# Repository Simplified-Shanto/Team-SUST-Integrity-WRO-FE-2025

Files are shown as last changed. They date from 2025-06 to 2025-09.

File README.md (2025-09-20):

# 👥 About the Team – **Team SUST Integrity**
---

## 👥 **Team SUST Integrity**

- **Nayeem Islam Shanto**  – Team Leader, Hardware Developer | [islamnayeem386@gmail.com](mailto:islamnayeem386@gmail.com)
- **Dipanjan Ghosh**  –  Schematic and Documentation Developer | [priomghosh33@gmail.com](mailto:priomghosh33@gmail.com)
- **L.M. Mahir Labib** – Software Developer | [labib.programmer@gmail.com](mailto:labib.programmer@gmail.com)

**Team Origin**: Bangladesh

---
# 📑 Table of Contents  

- [👥 About the Team – Team Integral Constant](#-about-the-team--team-integral-constant)  
  - [🧠 Who We Are](#-who-we-are)  
  - [📁 Repository Structure](#-our-repository-structure)  
- [🎯 Mission Overview](#mission-overview-for-wro-future-engineers-rounds)  
  - [🏁 Round 1: Lap Completion (Open Round)](#-round-1-lap-completion-open-round)  
  - [🚧 Round 2: Obstacle Challenge Round](#-round-2-obstacle-challenge-round)  
- [🧩 Hardware Components](#-hardware-components)  
- [🚗 Mobility Management](#-mobility-management)  
  - [🦾 Rear Axle Power Distribution](#-rear-axle-power-distribution)  
  - [🔁 Differential System](#-differential-system)  
  - [🧭 Steering Mechanism](#-steering-mechanism)  
- [💻 Raspberry Pi Setup](#-setting-up-raspberry-pi-for-image-processing-with-opencv--python)  
  - [🔑 Enabling & Using VNC](#-enabling--using-vnc-on-raspberry-pi)  
  - [🔎 Static COM Port Setup](#-how-to-set-static-com-port-for-the-low-level-microcontroller)  
  - [📷 Test Webcam Feed](#test-your-webcam-feed)  
  - [⚡ Auto-start Python Script](#running-your-python-script-on-startup-of-raspberry-pi)  
  - [🔌 Safe Shutdown via Serial](#safe-shutdown-for-raspberry-pi-via-serial-command)  
- [🧪 Testing & Calibration](#-testing--calibration)  
- [🔐 Safety Considerations](#-safety-considerations)  
- [🧑‍💻 Obstacle Challenge Strategy](#-strategy-for-the-obstacle-challenge-round)  

---

### 🧠 Who We Are

We are a group of passionate young engineers from Bangladesh, driven by curiosity, creativity, and a love for solving real-world problems with technology. Each team member plays a crucial role — from mechanical design to software development to integration testing.

This project reflects not just our technical skills, but our teamwork, perseverance, and belief in building meaningful things with limited resources.

---

### 📁 Our Repository Structure

To keep everything organized and transparent, we structured this GitHub repo with clarity and purpose. Here’s what each folder contains:

- `t-photos/`: Our official team photo and a fun team moment — because engineering is serious fun.
- `v-photos/`: Photos of the robot from all angles — top, bottom, front, back, sides — for full transparency.
- `video/`: Link to our demo and performance video.
- `schemes/`: Wiring and circuit diagrams, showcasing all sensors, modules, and power connections.
- `src/`: All the source code we wrote for robot control, sensors, PID logic, lap counting, and obstacle handling.
- `models/`: 3D printable parts, like sonar mounts and brackets — modeled in Autodesk Fusion 360.
- `Mobility Management/`: Our approach to movement — motor selection, differential system, steering design, and engineering principles.
- `Power and Sense Management/`: Detailed write-up of how power is distributed and how sensors are placed and calibrated.
- `Obstacle Management/`: Strategy for handling red and green blocks, including servo positioning and avoidance decisions.
- `other/`: Extra docs, debugging notes, component datasheets, or setup manuals — basically everything we couldn’t categorize neatly but didn’t want to lose.

---

### Mission Overview for WRO Future Engineers Rounds

<table>
  <tr>
    <td width="50%" valign="top" align="left">
      <h3>🏁 Round 1: Lap Completion</h3>
      <p>In <strong>Round 1</strong>, the robot must autonomously complete <strong>three laps</strong> on a pre-defined track. The goal of this round is for the bot to demonstrate stable navigation and precise lap tracking without any obstacle avoidance requirements.</p>
      <ul>
        <li><strong>Objective</strong>: Complete three laps on the track within the allotted time.</li>
        <li><strong>Key Tasks</strong>: Accurate path-following, speed control, and lap counting.</li>
      </ul>
      <div align="center">
        <br><br><br><br><br>
        Round 1 WRO Track
      </div>
    </td>
    <td width="50%" valign="top" align="left">
      <h3>🏆 Round 2: Lap Completion with Obstacle Avoidance and Parking</h3>
      <p>In <strong>Round 2</strong>, the bot must complete <strong>three laps</strong> while avoiding green and red obstacles:</p>
      <ul>
        <li><strong>Green Obstacles</strong>: The bot should move <strong>left</strong> to avoid.</li>
        <li><strong>Red Obstacles</strong>: The bot should move <strong>right</strong> to avoid.</li>
      </ul>
      <p>After completing the laps, the bot must accurately park within a designated zone.</p>
      <ul>
        <li><strong>Objective</strong>: Complete three laps, avoid obstacles, and park in the designated area.</li>
        <li><strong>Tasks</strong>: Obstacle detection, color-based avoidance, and precision parking.</li>
      </ul>
      <div align="center">
        Round 2 WRO Track
      </div>
    </td>
  </tr>
</table>

---
>[!IMPORTANT]
>**Important: WRO Future Engineers Rulebook**
>* **Thorough Reading:** Ensure that you thoroughly read the **WRO Future Engineers 2025 Rulebook** to understand all rules and guidelines.
>* **Official Link:** Access the rulebook here: [🔗 WRO Future Engineers 2025 Rulebook]([https://wro-association.org/competitions/future-engineers/](https://wro-association.org/wp-content/uploads/WRO-2024-Future-Engineers-Self-Driving-Cars-General-Rules.pdf).

---

# Strategy for the Challenge Rounds

## 👩‍💻 Strategy for the Open Challenge Round

In this round we mainly used sonar sensors to determine the position of the robot during driving straight and turning. We used a webcam for lap counting and also as a failsafe method for determining the position
of the robot when the data sent by the sonar sensors is inconsistent or in case of any malfunction.

- After starting the program the robot determines its placement on the track and its round direction(clockwise or anticlockwise).
- The sonar sensors attached to both sides of the robot help the robot to keep its position always at the center and the one attached in front of the robot helps it to turn smoothly by giving it ample data.
It is set to always turn right when round direction is clockwise and left when anticlockwise.
- The webcam mainly helps count the orange lines on the track to keep record of laps. After robot counts 12 orange lines(4 orange line = 1 lap) it determines the end of 3 laps.
- After traversing 3 laps it stops at its initial position after a certain amount of delay.

## 🏁 Round 1: Lap Completion (Open Round)

Here’s the process flow of how the robot completes laps in Round 1:

Open Round Process

---

## 🧑‍💻 Strategy for the Obstacle Challenge Round

Our current strategy for the Obstacle Challenge round is to avoid obstacles by changing the setpoint in the PID loop of our robot's main program.

- After the program starts the robot would at first determine the round direction(clockwise or anticlockwise) by observing which line(either orange or blue) comes first
- Then when it encounters a red object, it changes its setpoint from being into the middle towards the right wall(10 cm away from the right wall). The same approach is followed in case of a green object, only the difference being that it now follows the left wall.
- If it does not encounter any object the setpoint is again set to the center.

## 🚧 Round 2: Obstacle Challenge Round

Here’s the process flow of how the robot avoids obstacles in Round 2:

Obstacle Round Process

---

We built this robot and documentation not just for a competition, but to share, inspire, and collaborate. If you’re here to learn, contribute, or replicate — welcome to the constant.

# 🧩 Hardware Components

<div align="center">

| Component | Quantity | Image |
|---|:---:|:-----:|
| **Raspberry Pi 4B** | 1x |  |
| **ESP32 Dev Board** | 1x |  |
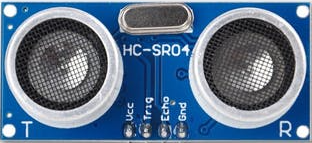
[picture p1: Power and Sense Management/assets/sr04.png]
| **HC-SR04 Ultrasonic Sensor** | 4x |  |
| **Raspberry Pi Camera Module** | 1x |  |
| **L298N Motor Driver Module** | 1x |  |
| **XL4016 Buck Converter** | 1x |  |
| **XL6009 Boost Converter** | 1x |  |
| **MG90S Micro Servo Motor** | 1x |  |
| **25GA 800RPM DC Geared Motor** | 1x |  |
| **MPU6050 Gyroscope Sensor** | 1x |  |

</div>
---

# 🚗 Mobility Management

Mobility is at the heart of our robot's design. We aimed to create a drive and steering system that mimics real-world vehicles while optimizing for speed, torque, and control on WRO tracks.

---

## 🦾 Rear Axle Power Distribution

We designed our rear-wheel drive system around **realistic mechanical dynamics**, utilizing a **LEGO differential gear** instead of a solid axle. This allows each wheel to rotate at different speeds during turns — just like in real cars — improving traction and reducing drag.

### 🔧 Motor Selection:
- We first experimented with standard **TT motors**, but they lacked the torque and RPM needed.
- We upgraded to **25GA 800 RPM DC geared motors**, which offer high torque and fast rotation, suitable for both lap completion and obstacle navigation.

---

## 🔁 Differential System

A **LEGO differential gear** is used on the rear axle. This gear allows independent rotation of the left and right wheels, providing:
- ✅ Smoother turning
- ✅ Reduced wheel slippage
- ✅ Real-world vehicle behavior emulation

The differential is connected directly to the 25GA motor, delivering balanced torque to both wheels.

---

## 🧭 Steering Mechanism

### ⚙️ Initial Design: Ackermann Steering

We initially implemented an **Ackermann Steering System**, commonly used in real vehicles. This system allows the inner and outer wheels to turn at different angles during cornering, minimizing slip and improving efficiency.

**Advantages:**
- ✅ Realistic turning geometry
- ✅ Efficient tire rotation paths

However, the mechanical complexity and setup space required made it difficult to tune within our chassis design.

---

### 🔄 Final Design: Rack and Pinion Steering

To simplify the design and enhance control, we transitioned to a **Rack and Pinion** steering system. This setup:
- Converts rotational motion from the steering motor to linear motion to turn the wheels
- Is simpler to mount and tune
- Offers consistent steering angles and tighter control

**Powered by:** Servo motor controlled by Raspberry Pi GPIO pins

---

## 🛠️ Chassis & Assembly Notes

- **Material**: Custom 3D printed base + LEGO Technic frame
- **Design Tools**: Autodesk Fusion 360 (for custom parts like sonar mounts, motor brackets)
- **Mounting Strategy**:
  - Front: Rack and pinion + servo motor
  - Rear: 25GA motor with LEGO differential
  - Components are evenly distributed for optimal center of mass

---

---

# 🚀 Setting Up Raspberry Pi for Image Processing with OpenCV & Python

You just unboxed a brand-new **Raspberry Pi**. Exciting! 🎉
Now let’s get it ready for image processing projects with OpenCV and Python.

---

## 🛠️ Initial Setup

1. **Download & Install Raspberry Pi Imager** on your computer.
2. In the **OS configuration menu**, set the following:

   * ✅ Hostname
   * ✅ Username
   * ✅ Password
   * ✅ Wi-Fi SSID & Password
   * ✅ Enable SSH
3. ✍️ Write down these credentials — you’ll need them for remote login later.
4. Once the OS image is written, insert the SD card into your Raspberry Pi and let it boot up.

---

## 🎮 Two Ways to Use Your Raspberry Pi

* **Option A**: Connect directly with an HDMI display, keyboard, and mouse.
* **Option B**: Connect remotely from your laptop/PC via **VNC (Virtual Network Computing)**.

We’ll focus on Option B since it’s super handy.

---

# 🔑 Enabling & Using VNC on Raspberry Pi

## 📡 Process 1: Connect via Ethernet Cable

1. Plug an **Ethernet cable** between your Raspberry Pi and your computer.
2. Wait until the **LAN port LEDs blink** — connection established!
3. On your computer, open **Command Prompt/Terminal**.
4. Type:

   ```bash
   ssh username@hostname
   ```

   Example:

   ```bash
   ssh admin@raspi.local
   ```
5. Enter your password when prompted.

💡 **What is SSH?**
SSH (Secure Shell) is a secure protocol that lets you remotely access and manage systems over a network. It encrypts communication to protect your data.

6. Once logged in, run:

   ```bash
   sudo raspi-config
   ```

   This opens a configuration menu:
   raspi-config-menu

7. Navigate to:
   **3 Interfacing Options → P3 VNC → Enable**
   enable-vnc

8. **Reboot** your Raspberry Pi.

9. On your computer, install & open **RealVNC Viewer**.

10. In the search bar, enter your Pi’s **hostname** (e.g., `raspi.local`).

11. First-time login will prompt for **username & password** → tick **“Remember Password”** if desired.

12. 🎉 You should now see the Raspberry Pi’s desktop GUI!

---

## 📶 Process 2: Connect via Wi-Fi (Wireless LAN)

1. Ensure your **Raspberry Pi** and **computer** are on the **same Wi-Fi network**.

   * If using a mobile hotspot, configure it with the same SSID & password you set during OS imaging.
2. Find your Raspberry Pi’s **IP address** on the network.

   * Tools like **Net Analyzer** (mobile app) make this easy.
3. From your computer, open Command Prompt/Terminal and type:

   ```bash
   ssh username@<raspberry-pi-ip>
   ```

   Example:

   ```bash
   ssh admin@10.149.112.111
   ```

   (Note: Here we use the **IP address**, not the hostname.)
4. Follow **Steps 7–12** from **Process 1** to enable VNC.
5. In RealVNC Viewer, enter the Pi’s **IP address**.
6. Log in with your username & password → check **“Remember Password”** if desired.
7. 🎉 The Raspberry Pi’s GUI should now appear on your computer!

---

✨ With VNC ready, you now have full graphical access to your Raspberry Pi — perfect for running **Python + OpenCV** image processing projects remotely!

---


  
   
   

# How to set static com port for the low level microcontroller?

---

## 🔎 Step 1: Plug in your ESP32 and identify it

First, connect your ESP32 to your Raspberry Pi’s USB port.
Then, open a terminal and run:

```bash
lsusb
```

You’ll see a list of connected USB devices, like this:


Take note of the **Vendor ID** (`1a86`) and **Product ID** (`7523`). These are your device’s fingerprints!

Now, let’s find its **serial number** (optional but recommended). Run:

```bash
udevadm info -a -n /dev/ttyUSB0
```

*(Replace `/dev/ttyUSB0` with the actual port assigned to your ESP32.Use the following command to find that)*


Look for lines like:

```
ATTRS{idVendor}=="1a86"
ATTRS{idProduct}=="7523"
ATTRS{serial}=="0001"  # Example
```

If your device has a serial number, use it to **uniquely identify** it, especially if you have multiple ESP32s.

---

## ✍️ Step 2: Create the udev rule

Create a new rule file in `/etc/udev/rules.d/`.
You can call it something like:

```bash
sudo nano /etc/udev/rules.d/99-esp32.rules
```

Inside, add this line (replace with your actual values):

```
SUBSYSTEM=="tty", ATTRS{idVendor}=="1a86", ATTRS{idProduct}=="7523", SYMLINK+="esp32_serial"
```

If you have a serial number too, add that:

```
SUBSYSTEM=="tty", ATTRS{idVendor}=="1a86", ATTRS{idProduct}=="7523", ATTRS{serial}=="0001", SYMLINK+="esp32_serial"
```

This means:

* Whenever a device with **Vendor ID 1a86** and **Product ID 7523** is connected, udev will create a **symlink** (like an alias) at `/dev/esp32_serial`.

---

## 🔄 Step 3: Reload udev and test it

Reload udev rules:

```bash
sudo udevadm control --reload-rules
```

Then **unplug and plug back** your ESP32.

Check:

```bash
ls -l /dev/esp32_serial
```

You should see something like:

```
lrwxrwxrwx 1 root root 7 Jun 10 16:23 /dev/esp32_serial -> ttyUSB0
```

(Or whatever tty device it points to.)

---

## 🐍 Step 4: Use it in your Python script

Now, in your script:

```python
import serial

ser = serial.Serial('/dev/esp32_serial', 115200)
```

This way, no matter what port it lands on—`ttyUSB0`, `ttyUSB1`, `ttyACM0`—you’ll always connect using `/dev/esp32_serial`.

---

# Install python modules like opencv, numpy, time, pyserial using following command: 
sudo apt install python3-opencv python3-numpy python3-serial

## 🚀 Pro Tips

✅ If your ESP32 shows up as `/dev/ttyACM0` instead of `/dev/ttyUSB0`, adjust your `udevadm info` command accordingly.
✅ Use `udevadm monitor` to see real-time device events:

```bash
udevadm monitor --udev
```

---

---

## Test Your Webcam Feed

Before running the full OpenCV script, it’s important to make sure your camera is working properly. This avoids unnecessary debugging later if the issue is just with the webcam feed.

### Steps:

1. Make sure your Raspberry Pi is set up and your webcam is connected.

2. Install OpenCV for Python (if not already done):

   ```bash
   pip install opencv-python
   ```

3. Create a new Python file called `test_camera.py` and paste the following code:

   ```python
   import cv2

   cap = cv2.VideoCapture(0)  # 0 is usually the default camera

   if not cap.isOpened():
       print("Error: Could not open camera.")
       exit()

   while True:
       ret, frame = cap.read()
       if not ret:
           print("Error: Failed to capture frame.")
           break

       cv2.imshow("Webcam Feed", frame)

       # Press 'q' to exit the window
       if cv2.waitKey(1) & 0xFF == ord('q'):
           break

   cap.release()
   cv2.destroyAllWindows()
   ```

4. Run the script:

   ```bash
   python test_camera.py
   ```

5. A window should pop up showing your live webcam feed.

   * If you see the video feed, your camera is working fine.
   * If you don’t, check if your camera is properly connected and detected by the system using:

     ```bash
     ls /dev/video*
     ```

---

---

# Running your Python Script on Startup of Raspberry Pi

If you want your Python script to automatically run when your Raspberry Pi boots up (without needing a monitor, keyboard, or VNC), follow these steps. We’ll use a **systemd service**, which is the recommended modern way.

---

## 1. Locate Your Script

Make sure your Python script is at the correct path. In this guide, we’ll assume your script is here:

```
/home/admin/Desktop/startscript.py
```

Check that the script has a proper shebang at the top (this tells Linux to use Python 3):

```python
#!/usr/bin/env python3
```

---

## 2. Make the Script Executable

Run this command in the terminal:

```bash
chmod +x /home/admin/Desktop/startscript.py
```

---

## 3. Create a systemd Service File

Create a new service definition:

```bash
sudo nano /etc/systemd/system/startscript.service
```

Paste the following:

```ini
[Unit]
Description=Startscript for Line Counter
After=multi-user.target

[Service]
ExecStart=/usr/bin/python3 /home/admin/Desktop/startscript.py
WorkingDirectory=/home/admin/Desktop
StandardOutput=append:/home/admin/startscript.log
StandardError=append:/home/admin/startscript.log
Restart=always
RestartSec=5
User=admin

[Install]
WantedBy=multi-user.target
```

If you want the program run once per boot, make Restart=no and remove the line RestartSec=5. 
This won't allow it to rerun the program if it ends its execution by some internal logic, command or crashes in the same boot session. 

Save and exit (`CTRL+O`, `ENTER`, `CTRL+X`).

---

## 4. Enable the Service

Reload systemd and enable your new service so it runs on every boot:

```bash
sudo systemctl daemon-reload
sudo systemctl enable startscript.service
```

You can start it immediately (without rebooting) using:

```bash
sudo systemctl start startscript.service
```

---

## 5. Check Logs and Status

* Check if your script is running:

  ```bash
  systemctl status startscript.service
  ```
* View live logs:

  ```bash
  journalctl -u startscript.service -f
  ```
* Or check the saved log file:

  ```bash
  cat /home/admin/startscript.log
  ```

---

## 6. Stop or Disable Later

To stop the script from running:

```bash
sudo systemctl stop startscript.service
```

To remove it from startup:

```bash
sudo systemctl disable startscript.service
```

---

✅ That’s it! Your Python script will now start automatically whenever your Raspberry Pi boots up — even without HDMI or network connected.

---

# Safe Shutdown for Raspberry Pi via Serial Command

Normally, if you unplug the power from your Raspberry Pi without shutting it down first, you risk corrupting the SD card or losing data. To prevent this, the Pi should always be shut down properly before the power is removed.

In this setup, we achieve a graceful shutdown without needing a display (HDMI) or remote access (VNC/SSH).

How it works

A low-level microcontroller (e.g., Arduino/ESP) detects a trigger event (such as a button press, sensor signal, or external condition).

It sends a shutdown command over Serial (UART/USB) to the Raspberry Pi.

A Python script running on the Pi (using PySerial
) listens for this command.

Once received, the script executes:

sudo shutdown now

The Pi powers down safely, protecting the filesystem and ensuring no data loss.

Why this matters

✅ Prevents SD card corruption caused by abrupt power cuts

✅ Works without a monitor, keyboard, or VNC session

✅ Can be triggered by just a button press or any hardware event handled by the microcontroller

---
## 🧪 Testing & Calibration

- ✅ PID tuning done for lap accuracy
- ✅ Rack and pinion tested for max steering angle and stability
- ✅ Motors calibrated for obstacle response delay and RPM

---

## 🔐 Safety Considerations

- All electrical joints are soldered and insulated
- Gear systems are housed to prevent accidental entanglement
- Battery is securely mounted with a cutoff mechanism

---

By combining a **25GA high-RPM motor**, **LEGO differential**, and a **custom rack and pinion system**, our robot delivers realistic movement, efficient turning, and powerful drive — ready for the WRO Future Engineers challenge.

---

## 📜 License

© 2025 Team SUST Integrity – WRO Future Engineers  
This project is licensed under the [MIT License](LICENSE).

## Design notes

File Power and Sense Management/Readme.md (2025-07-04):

**Power and Sense Management**
====
In the realm of robotics, effective power and sense management is the linchpin of our robot's performance. Our cutting-edge system ensures optimal resource allocation, revolutionizing how robots interact with their surroundings.

## 1. Power Management: 

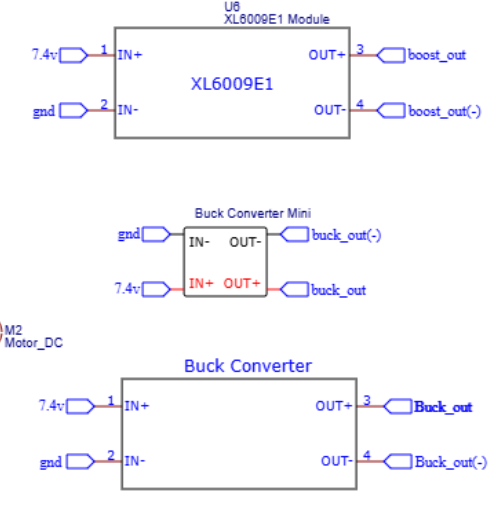
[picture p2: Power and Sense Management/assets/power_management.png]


   At first from lithium ion cell we are fetching 3.7v and being 12v by XL60009. then HW-411A LM2596 are cosuming power to 3.3v for the sensor e.g. Pi Camera, SR04 ultrasonic sensor and gyro-sensor MPU 6050.  Laterby we are suplying 5v to servo 12v to BTS7960 and motor being powered to.
## 2. Sensors: 
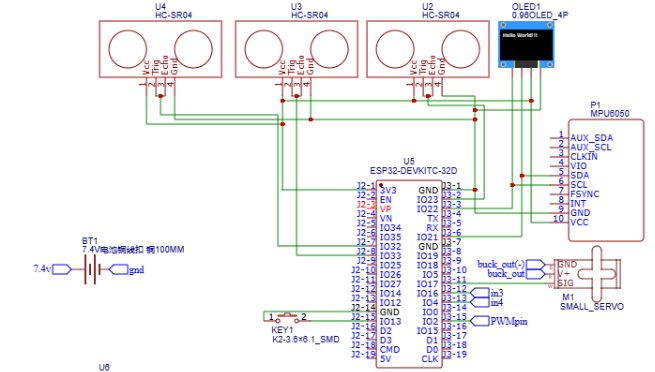
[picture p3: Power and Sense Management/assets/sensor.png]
Sensor


- #### **Ultrasonic Sensor:**
   

   The SR04 is an ultrasonic distance sensor used for measuring distances. We're powering it with a stable 5V supply obtained from an HW-411A LM2596 voltage regulator connected to an 11.1V LiPo battery. This setup ensures reliable distance measurements and efficient power management for our robot.

- #### **Pi Camera:**
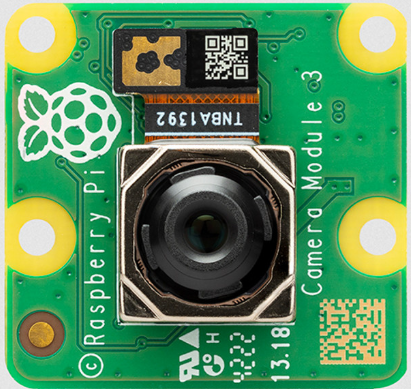
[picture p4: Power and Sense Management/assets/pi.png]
  

The Raspberry Pi Camera is a high-definition vision module capable of capturing images and streaming video, commonly used in robotics and computer vision applications. In our configuration, we use the Raspberry Pi Camera Module connected to a Raspberry Pi 4B, which serves as the core processing unit for advanced image processing tasks. The camera interfaces directly with the Raspberry Pi via the CSI (Camera Serial Interface) port, enabling high-speed data transfer. 
- #### **gyro-sensor:**
  MPU

The MPU6050 is a popular gyro-sensor and accelerometer sensor used for motion sensing and orientation tracking in various applications, including robotics and motion-controlled devices. In our setup, the MPU6050 is powered by a 5V supply sourced from an ESP32 Dev Board, which itself receives power from an HW-411A LM2596 voltage regulator. This HW-411A LM2596 regulator is connected to an XL60009 module, and the entire system is powered by an 3.7V lithium ion cell.

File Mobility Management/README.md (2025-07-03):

# Mobility Management

In the realm of mobility management for our vehicle, we meticulously select and implement motors based on engineering principles like speed, torque, and power, while also considering chassis design and component mounting for optimal performance. Assembly instructions and 3D CAD files are available for easy part fabrication.

## Motor Selection and Implementation:

### 1. Motor Selection:
- We initially experimented with **TT motors**, but they did not meet the required torque and speed benchmarks.
- Upgraded to **24GA 800 RPM DC Geared Motors**, offering improved torque output and higher rotational speed for stable and responsive movement.
- To replicate real-world vehicle behavior, we used a **LEGO differential gear** on the rear axle instead of a solid axle. This allows the rear wheels to rotate at different speeds during turns, providing smoother and more realistic cornering.

### 2. Motor Controller:
- The **L298N motor driver** was selected for its high current capacity and smooth PWM-based motor control.
- Integrated seamlessly with our **ESP32-based** microcontroller.

### 3. Implementation:
- Motors were wired to the motor driver, and the driver was interfaced with the ESP32 Dev Board.
- The rear axle was integrated with a LEGO differential system to enable differential wheel speeds during turning.

---

## Front Axle Steering System:

- Initially, we implemented an **Ackermann steering geometry**, which is known for replicating realistic vehicle steering angles and minimizing tire slippage during turns.
- After testing, we transitioned to a **Rack and Pinion steering system**, which offered better mechanical simplicity and precision for our use case.
- The rack and pinion system was designed using 3D CAD software and fabricated to ensure tight control over steering angle and response.

---

## Chassis Design and Selection:

### 1. Chassis Material:
- Constructed from **plastic base material** to ensure weightlessness and durability.

### 2. Chassis Shape:
- Optimized to accommodate all internal components while maintaining stability and proper ground clearance.

### 3. Mounting Components:
- Components were strategically arranged for even weight distribution and accessibility.
- Major mounted components include:
  - 24GA Motors with LEGO Differential Gear
  - Rack and Pinion Steering Mechanism
  - Ultrasonic and IR Sensors
  - MPU6050 Gyroscope Sensor
  - Pi Camera
  - ESP32-based Control Board
  
### 4. Engineering Principles:
- Careful calculation of **center of mass**, **wheelbase**, and **track width** to ensure stability and effective turning.
- The differential and rack & pinion systems improved the maneuverability and reduced strain on tires during sharp turns.

---

## Building and Assembly Instructions:

### 1. Step-by-Step Assembly:
- Detailed step-by-step guide covering chassis assembly, drivetrain mounting, and steering linkage.
- Wiring diagrams are provided for connecting all sensors, motors, and control components.

### 2. 3D Printed Parts:
- Custom-designed components (e.g., sonar mount, wheel rims, rack gear) were modeled using **Autodesk Fusion 360**.
- STL files and recommended materials/settings are available in the `models/` directory.

### 3. Testing and Calibration:
- Procedures for:
  - Steering calibration (center alignment, turning angles)
  - Motor speed tuning
  - Sensor data verification and orientation

### 4. Safety Considerations:
- Emphasized safety while handling LiPo batteries, high-speed motors, and voltage converters.
- All exposed connections were insulated and stress-tested under load.

---

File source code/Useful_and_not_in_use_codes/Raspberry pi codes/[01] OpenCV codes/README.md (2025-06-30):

Distance calculation logic
---

### 🔍 **Core Formula Used**

```python
distance_cm = (KNOWN_WIDTH_CM * FOCAL_LENGTH) / perceived_width_px
```

This is based on the **pinhole camera model** from computer vision.

---

### 🎯 What Each Term Means:

| Term | Explanation |
| --- | --- |
| `KNOWN_WIDTH_CM` | Real-world width of the object (10 cm for WRO traffic signs) |
| `FOCAL_LENGTH` | Calibrated or estimated focal length of the camera in pixels |
| `perceived_width_px` | Width of the object in the image (bounding box) — measured in pixels |

---

### 🧠 **The Logic Behind It**

From the geometry of a pinhole camera:

$$
\frac{\text{Real Width (cm)}}{\text{Image Width (px)}} = \frac{\text{Real Distance (cm)}}{\text{Focal Length (px)}}
$$

Rearranged:

$$
\text{Distance (cm)} = \frac{\text{Real Width (cm)} \times \text{Focal Length (px)}}{\text{Image Width (px)}}
$$

---

### 📏 Why This Works here

Since your traffic signs are **known and consistent in size (10 cm width)**, this formula works beautifully — assuming:

* The sign is facing the camera.
* There’s not too much tilt or perspective distortion.
* You’ve calibrated the `FOCAL_LENGTH` once using a known object at a known distance.

---

### 🎨 What About Aspect Ratio?

The aspect ratio check here:

```python
if not (1.6 <= rect_aspect <= 2.4):
    continue
```

✅ **Purpose**:
To filter out **false positives** — ensuring that the shape found in the frame **looks like the real traffic sign**, which has a **2:1 aspect ratio** (height\:width or vice versa depending on orientation).

So you're not using the aspect ratio **in the distance formula**, but rather as a **guard** before measuring distance — to avoid calculating distances to random rectangles like tiles, floor patterns, or odd shadows.

---

### 📸 About Focal Length: How Is `700` Chosen?

The value `700.0` is not universal — it’s typically:

  * **Estimated experimentally**, by measuring an object of known width at a known distance and solving:

  $$
  \text{Focal Length (px)} = \frac{\text{Perceived Width (px)} \times \text{Distance (cm)}}{\text{Real Width (cm)}}
  $$

  * Or derived via camera calibration if you're being fancy.

📏 **Quick way to calibrate** with your 10 cm column:

* Place it exactly 50 cm from the camera.
* Measure its bounding box width on the image: e.g. 35 pixels.
* Use:

$$
\text{FOCAL LENGTH} = \frac{35 \times 50}{10} = 175.0
$$

So your `700.0` might assume a different scale or higher-resolution camera — feel free to recalibrate!

---

###  Summary:

* ✅ **Aspect ratio**: used as a filter to ensure you’re detecting the right-shaped object (around 2:1 like your columns).
* ✅ **Focal length**: used to convert image width in pixels into a real-world distance in centimeters.
* ✅ **Distance logic**: classic pinhole camera projection formula, ideal when you know the real object size (which WRO gives you 😎).

---

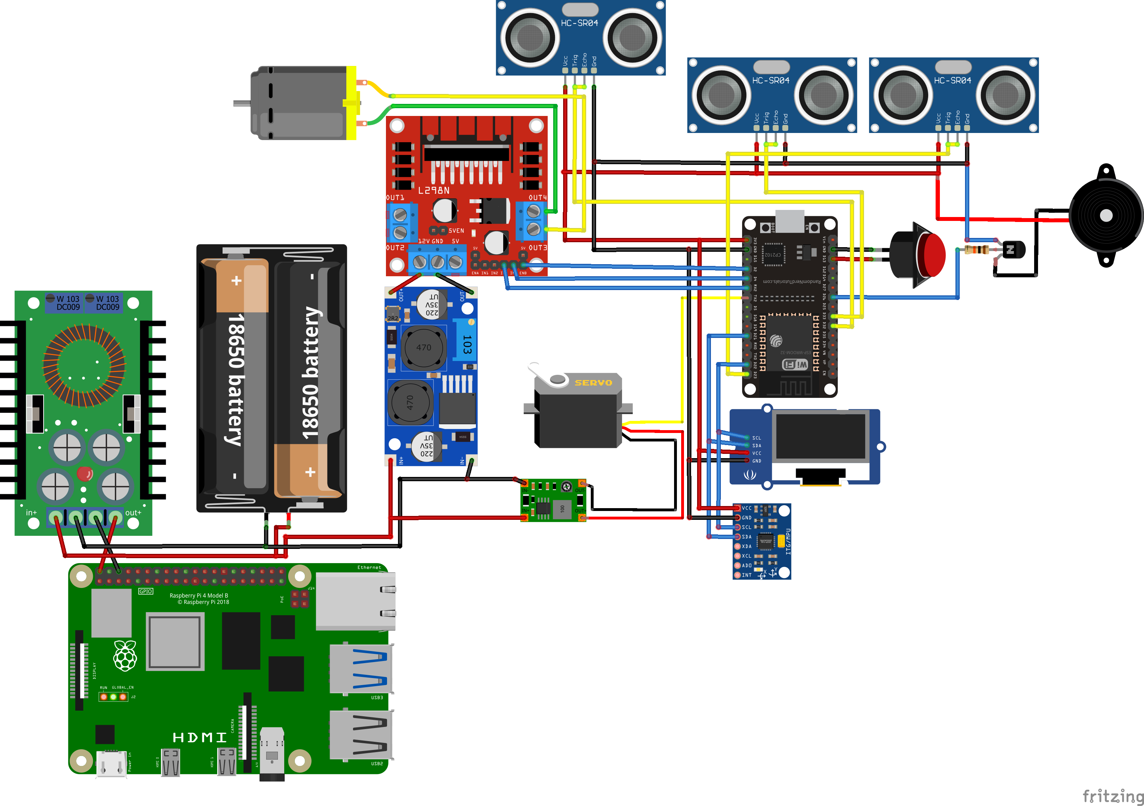
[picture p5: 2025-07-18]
schematic/Visual_Circuit.png

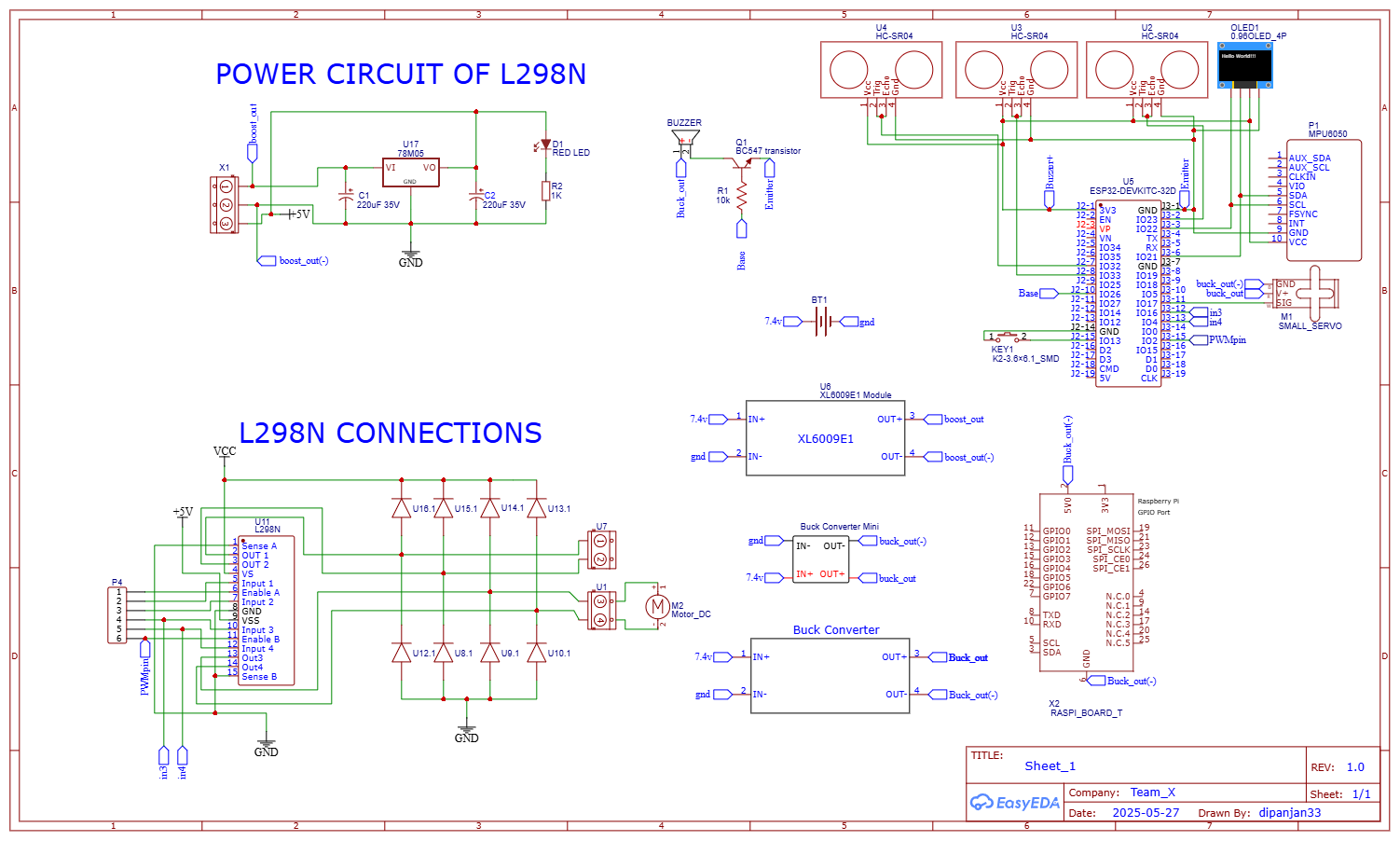
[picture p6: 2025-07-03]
schematic/Schematic_Diagram.png

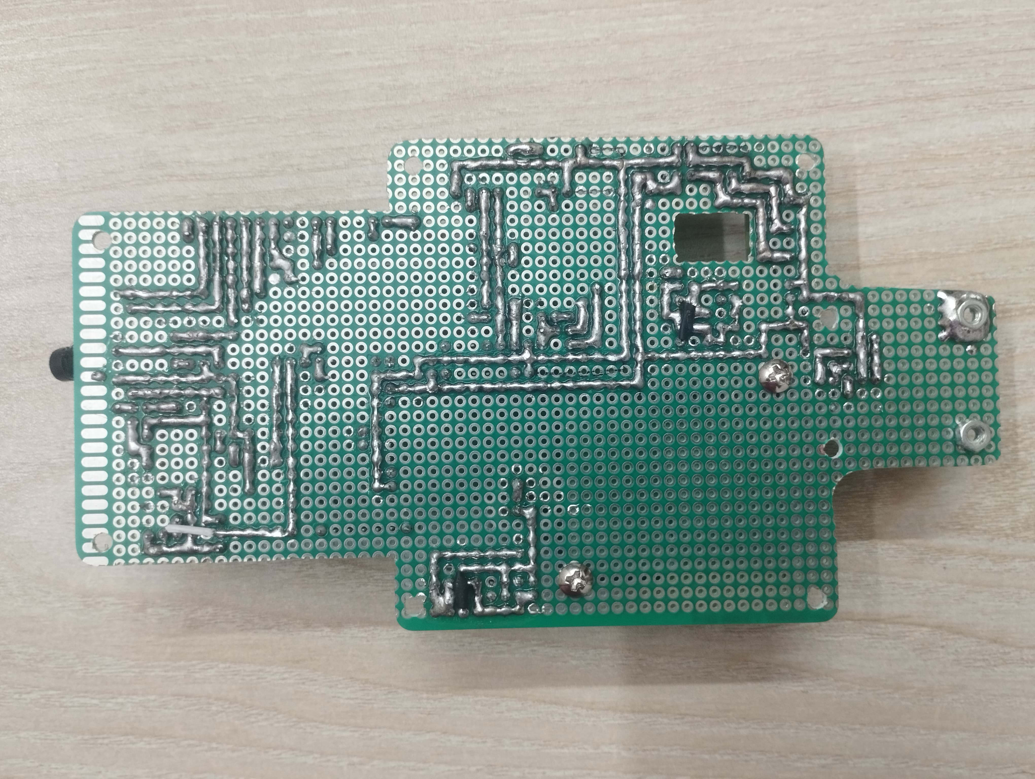
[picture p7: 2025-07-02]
schematic/circuit - bottom view.jpg

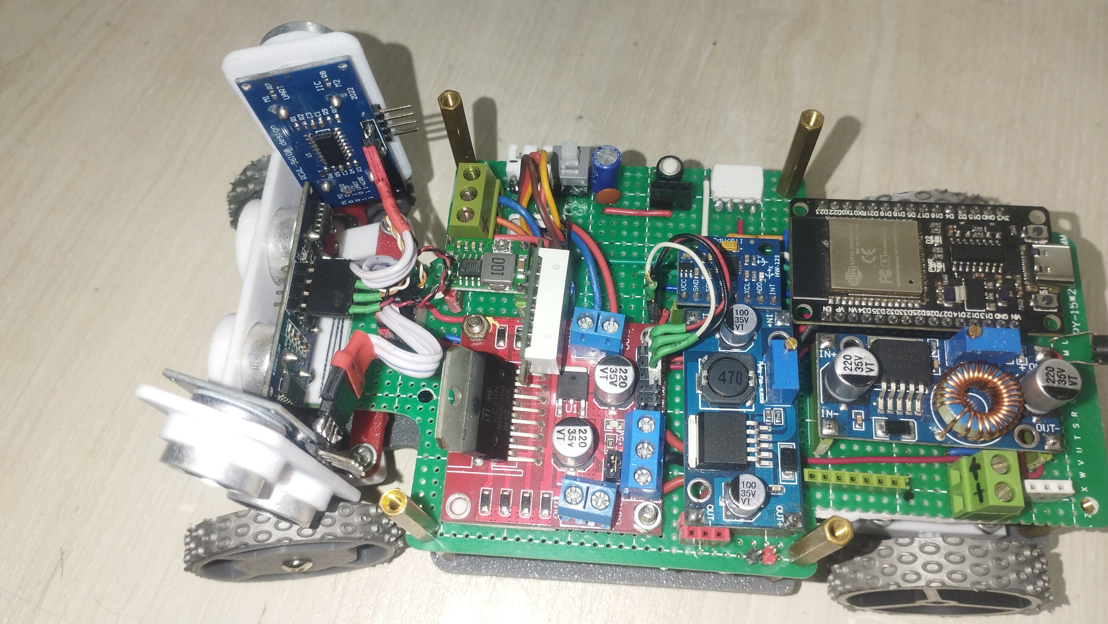
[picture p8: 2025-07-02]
schematic/circuit - top view.jpg

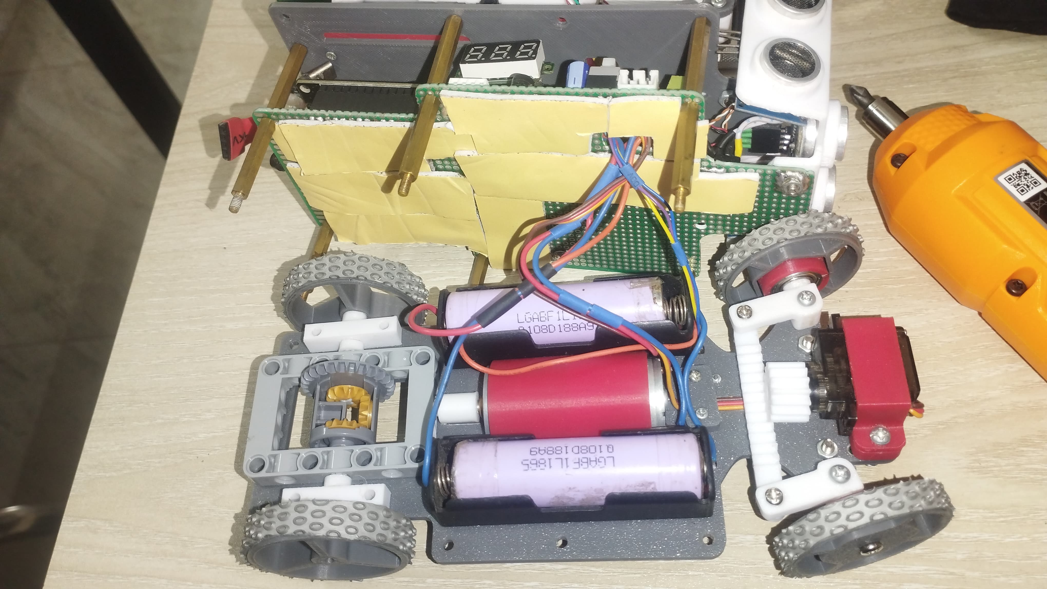
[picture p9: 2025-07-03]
Mobility Management/assets/run control unit.jpg

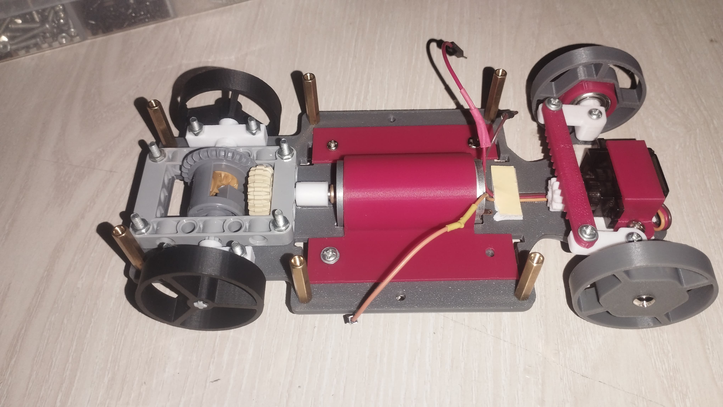
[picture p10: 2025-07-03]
Mobility Management/assets/gearbox.jpg

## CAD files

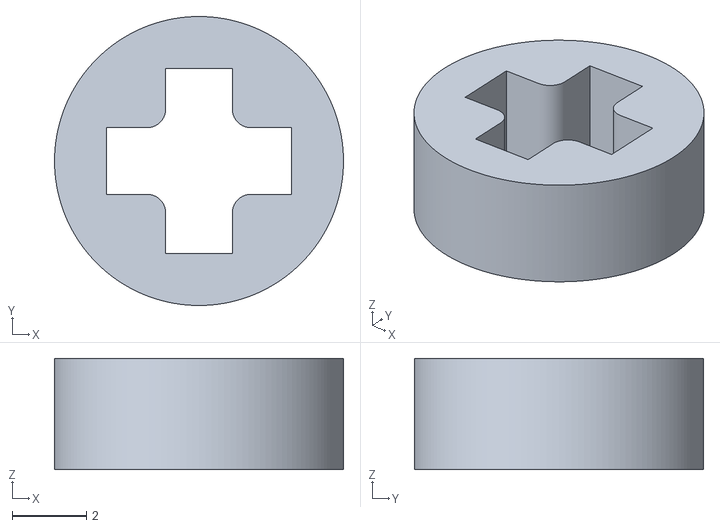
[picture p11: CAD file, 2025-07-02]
models/3mm lego stopper.stl
7.80 x 7.80 x 3.00

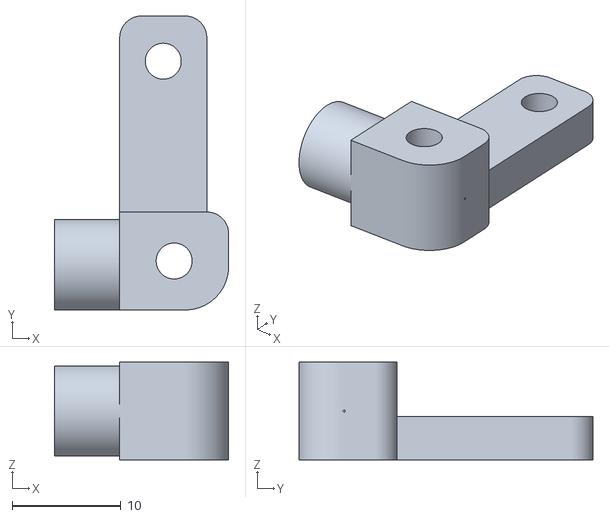
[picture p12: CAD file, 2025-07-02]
models/left axle.stl
16.0 x 27.0 x 9.00

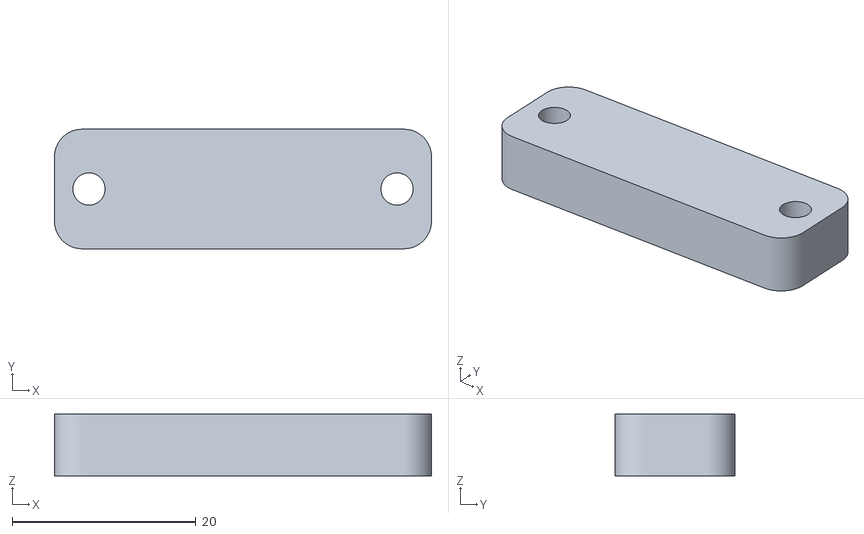
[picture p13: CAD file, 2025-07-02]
models/Servo motor elavation stage.stl
41.0 x 13.0 x 6.70

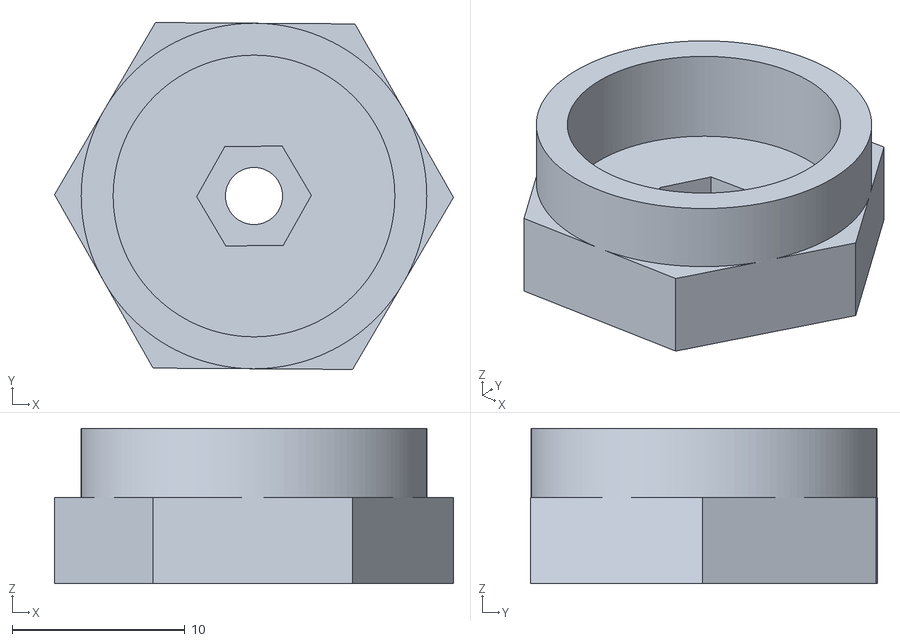
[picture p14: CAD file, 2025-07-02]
models/wheel holder hex.stl
23.1 x 20.1 x 9.00

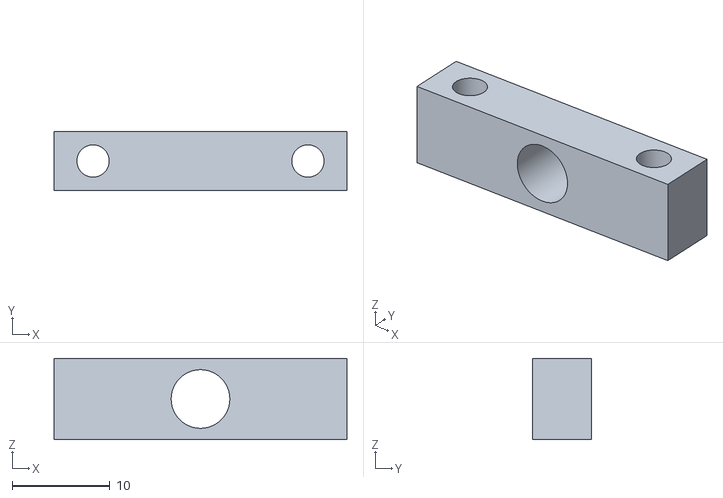
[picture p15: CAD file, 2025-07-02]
models/Rear axle holder.stl
30.0 x 6.00 x 8.30

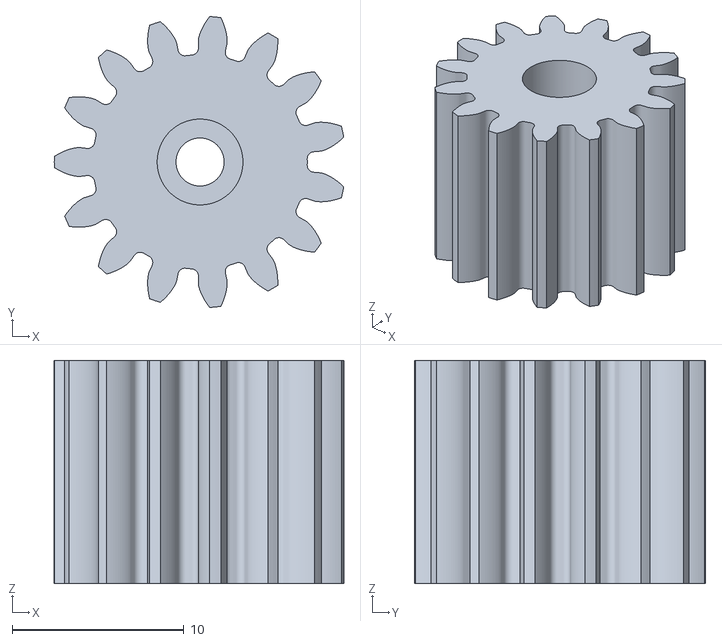
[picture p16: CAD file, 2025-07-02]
models/Pinion.stl
16.9 x 17.0 x 13.0

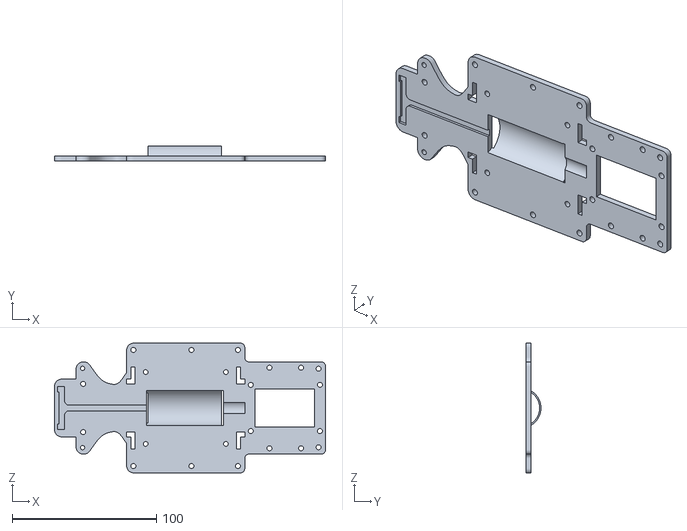
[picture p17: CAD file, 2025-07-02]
models/Chasis.stl
188.0 x 10.4 x 90.0

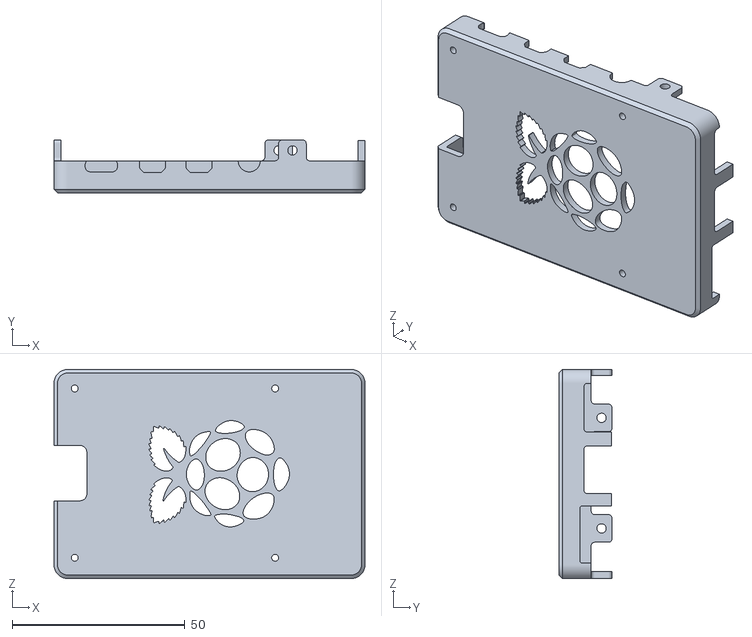
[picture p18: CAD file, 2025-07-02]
models/raspberrypie case bottom.stl
90.0 x 15.3 x 60.5

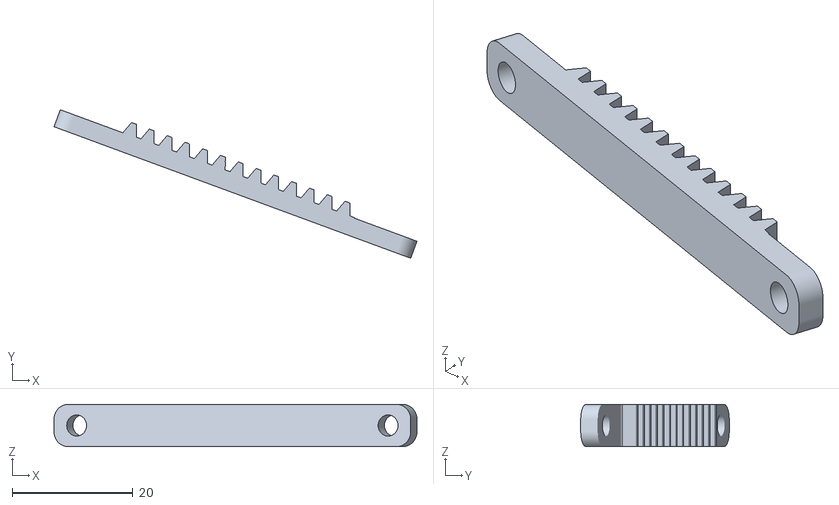
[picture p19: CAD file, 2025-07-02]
models/Rack.stl
60.1 x 24.6 x 7.00

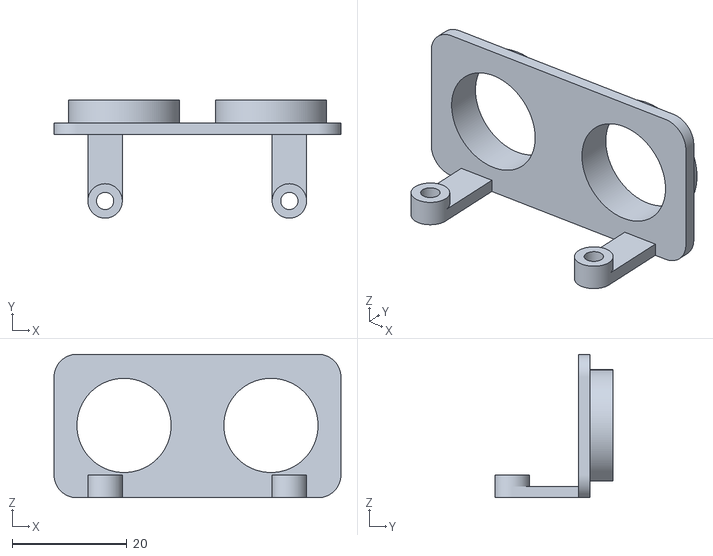
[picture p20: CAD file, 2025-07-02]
models/Back sonar holder.stl
50.0 x 20.6 x 25.0

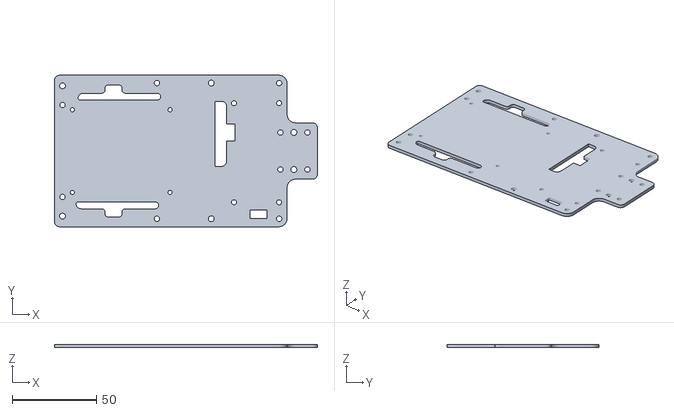
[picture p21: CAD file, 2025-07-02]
models/top layer.stl
156.0 x 89.9 x 2.00

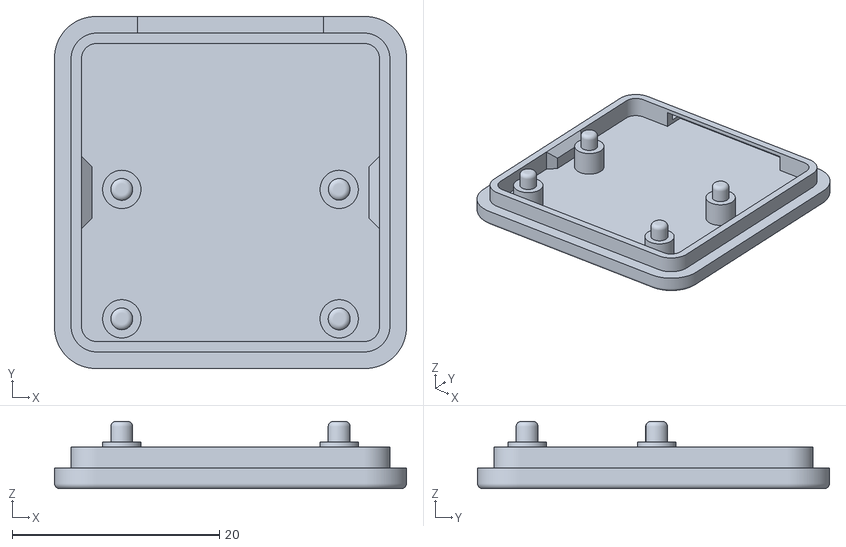
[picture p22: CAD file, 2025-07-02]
models/RaspberryPie_Camerav1_case_back.stl
34.0 x 34.0 x 6.50

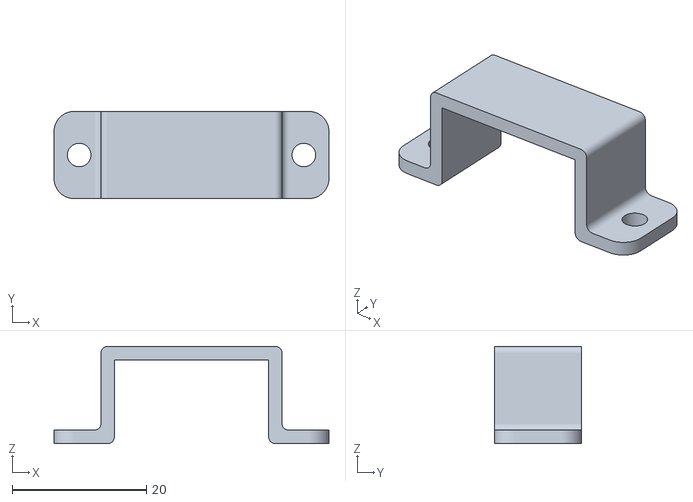
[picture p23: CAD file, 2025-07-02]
models/sg90 Servo holder.stl
41.0 x 13.0 x 14.5

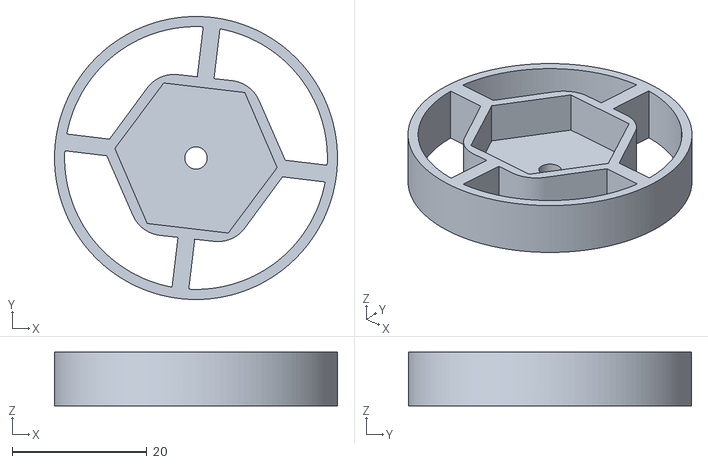
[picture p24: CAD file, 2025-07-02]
models/Front wheel.stl
42.0 x 42.0 x 8.00

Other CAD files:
models/right axle.stl
models/Pie camera stand.stl
models/Sonar sensor holder.stl
models/Pie camera case front.stl
models/Motor cover.stl
models/MotorShaft-Gear linker.stl
models/Rear wheel.stl

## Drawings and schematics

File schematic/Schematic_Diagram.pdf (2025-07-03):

# POWER CIRCUIT OF L298N

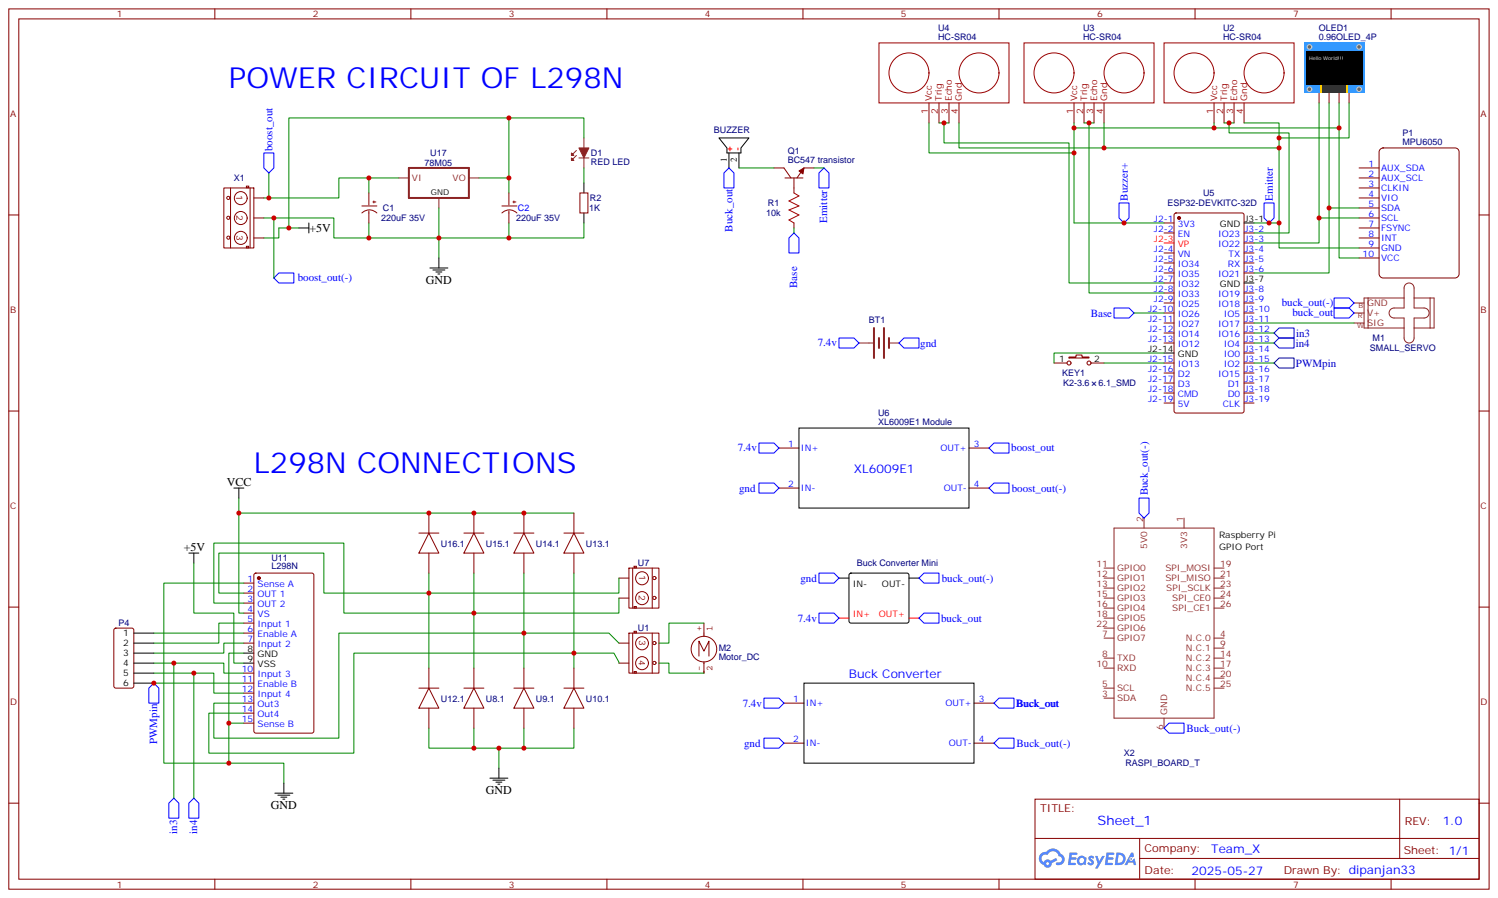
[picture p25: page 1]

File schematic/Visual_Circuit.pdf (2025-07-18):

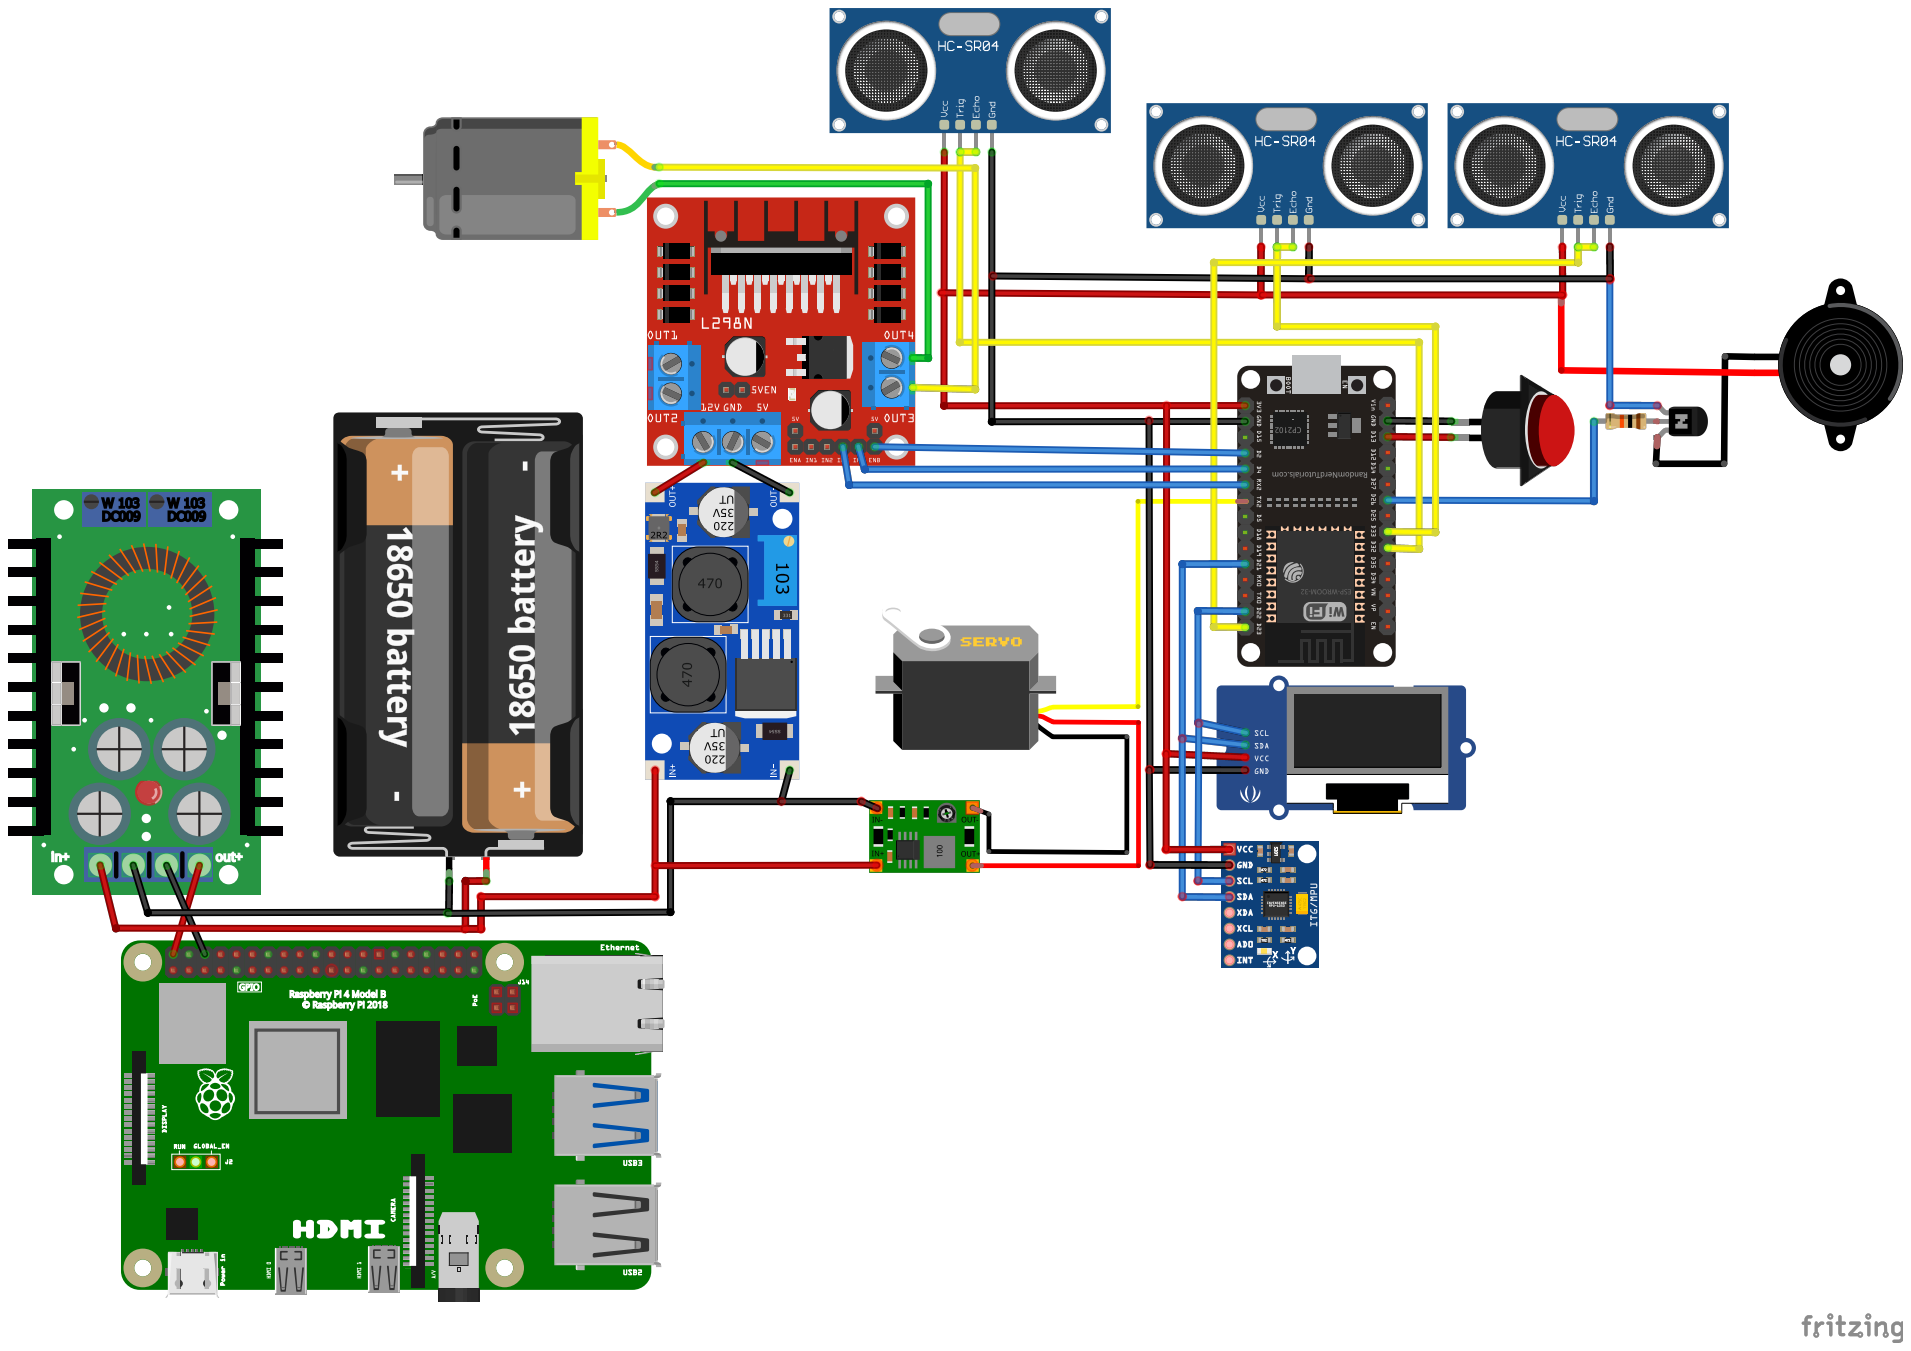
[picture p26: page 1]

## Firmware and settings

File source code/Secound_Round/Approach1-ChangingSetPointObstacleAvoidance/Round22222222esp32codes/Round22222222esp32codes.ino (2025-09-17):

//Board: esp32 by Espressif Systems. Version: 1.0.3
//ESP32Servo by Kevin, Harrington, John K. Benett. Version: 3.0.6
//NewPing by Tim Eckel. Version: 1.9.7
//Adafruit GFX Library by Adafruit. Version: 1.12.0
//Adafruit SSD1306 by Adafruit. Version: 2.5.13

#include <Preferences.h>
#include "motors.h"
#include "button.h"
#include "servo_motor.h"
#include "sonar.h"
#include "display.h"

Preferences preferences;
double Kp = 3;    //5
double Kd = 0.3;  //1
double Ki = 0;
int lineInterval = 1000;  //time (ms) to wait in the image processing programme between lines counted.
int stopDelay = 1000;     //when 12 lines are counted, the SBC sends the lap complete command after this fixed delay(ms)
double value = 0;         // Stores the difference between the left and right readings.
double error = 0;         // The difference between value and setpoint.
double lastError = 0;
double PIDangle = 0;
double integralError = 0;

#define parameterCount 9  // Number of configurable parameters

unsigned int redObstacleDistance = 0;
unsigned int greenObstacleDistance = 0;


double setPoint = 0;  // The amount of difference in reading of the two ultrasonic sensor we want.
//Above one is the initial setPoint which keeps the vehicle centered in a tunnel
double dynamicSetPoint = 0;  //This setpoint is assigned after determining the run direction
int setPointMultiplier = 1;  // -1 = round is clockwise 1 = round is anticlockwise
int terminalDistanceThreshold = 200;
short restrictedSteer = 35;
short unrestrictedSteer = 40;
int steerAngle = restrictedSteer;  // steerAngle = maximum angle used for steering currently



void setup() {
  Serial.begin(115200);
  preferences.begin("wrobot", false);
 // preferences.clear();  //Only uncomment it when you have the first round code uploaded currently. Upload this code. Then comment this line again.
  lineInterval = preferences.getInt("lineInterval", lineInterval);
  stopDelay = preferences.getInt("stopDelay", stopDelay);
  Kp = preferences.getDouble("Kp", Kp);
  Ki = preferences.getDouble("Ki", Ki);
  Kd = preferences.getDouble("Kd", Kd);
  forwardSpeed = preferences.getInt("speed", forwardSpeed);
  restrictedSteer = preferences.getShort("restrictedSteer", restrictedSteer);
  unrestrictedSteer = preferences.getShort("urSteer", unrestrictedSteer);

  pinMode(ledPin, OUTPUT);
  pinMode(buttonPin, INPUT_PULLUP);
  pinMode(button2Pin, INPUT_PULLUP);
  pinMode(buzzerPin, OUTPUT);
  digitalWrite(buzzerPin, LOW);

  ESP32PWM::allocateTimer(0);
  steering_servo.setPeriodHertz(50);                     // standard 50 hz servo
  steering_servo.attach(steering_servo_pin, 500, 2400);  // attaches the servo on pin 18 to the servo object
  steering_servo.write(midAngle);
  delay(1000);

  ledcSetup(LEDC_CHANNEL, 1000, 8);     // Set LEDC channel, frequency, and resolution
  ledcAttachPin(pwmPin, LEDC_CHANNEL);  // Attach the GPIO pin to the LEDC channel
  pinMode(in1Pin, OUTPUT);
  pinMode(in2Pin, OUTPUT);

  display.begin(SSD1306_SWITCHCAPVCC, 0x3C);
  display.setTextColor(1);
  display.setTextSize(1);
  showParameters();
}

bool button2Flag = 0;
bool button1Flag = 0;
long long pressTime2 = millis();
long long pressTime1 = millis();
bool editParameter = 0;
short parameterIndex = 0;  // 0  = Speed, 1 = Kp, 2 = Kd
short leftDistance = 0;
short rightDistance = 0;
short frontDistance = 0;
int roundDirection = 0;  // 0 = clockwise 1 = ccw


void loop() {
  if (Serial.available()) {
    String command = Serial.readStringUntil(';');
    handleSerialCommand(command);
  }
  rightDistance = rightSonar.ping_cm();
  leftDistance = leftSonar.ping_cm();
  frontDistance = frontSonar.ping_cm();
  /*


    There's a problem with the following conditioning, if anyhow side sonar fails to be zero when its time to turn, the vehicle will always take left turn. 
      
      If we know the round direction, we can disable taking turn in left or right side at corners, reducing the error possibility. 
      
      Can we anyhow use the gyro sensor to determine the round direction very reliably?  The car goes parallely for the time being at the starting. 

      Can we anyhow avoid obstacle from the right side, or change setPoint properly without knowing the round direction ? Using any opencv mechanism. 

      For now, since we've the camera facing downward, and detecting lines, we can solfe the counter-clockwise turning problem. 

      The counter-clockwise turning problem is arising from the fact that, the frontDistance condition checking is being true before the side sonar being zero condition is hitting the ground. 
      We can also try to solve the problem first by reducing the front distance threshold. So we'll be primarily relying on the side sonars for turning and then in any case if it fails, 
      then the front distance checking will start the turning attempt. With this combine the one side turning only mechanism at corners, and things should work properly. 

  */


  //Mechanism 2:

  if (setPoint != 0 || rightDistance == 0 || leftDistance == 0 || (frontDistance != 0 && frontDistance < frontDistanceThreshold))  //Take a turning action on any of these events.
  {
    steerAngle = unrestrictedSteer;
    if (setPoint != 0) {
       // We need to devise some logic here, to avoid wall hits, overturning etc things when the steering is still being done by the changed setpoint. 
    } else if (rightDistance == 0 && leftDistance != 0)  // 1 0
    {
      rightDistance = terminalDistanceThreshold;
      digitalWrite(buzzerPin, LOW);
    } else if (leftDistance == 0 && rightDistance != 0)  //0 1
    {
      leftDistance = terminalDistanceThreshold;
      digitalWrite(buzzerPin, LOW);
    } else if (leftDistance != 0 && rightDistance != 0)  //1 1
    {
      if (leftDistance > rightDistance) {
        leftDistance = terminalDistanceThreshold;
      } else if (rightDistance > leftDistance) {
        rightDistance = terminalDistanceThreshold;
      }
      digitalWrite(buzzerPin, LOW);
    } else if (leftDistance == 0 && rightDistance == 0) {  //0 0 Both sonar sensor is reading zero, so we are resorting to the round direction for taking turns.
      if (gameStarted == 1) {                              // Notifying that both sensor is currently reading zero.
        digitalWrite(buzzerPin, HIGH);
      }
      if (setPointMultiplier == -1) {  //cw round
        rightDistance = terminalDistanceThreshold;
      } else if (setPointMultiplier == 1) {  //ccw round
        leftDistance = terminalDistanceThreshold;
      } else if (setPointMultiplier == 0)  // Round direction haven't been determined yet
      {
        //Do nothing, we don't know what to do now.
      }
    }
  } else {
    steerAngle = restrictedSteer;
  }


  handleButtonPress();
  integralError += error;
  // optional: limit integral to prevent windup
  if (integralError > 1000) integralError = 1000;
  if (integralError < -1000) integralError = -1000;
  //   67         84,             7   -> When the vehicle follows the right wall
  //  -67         7 ,            84   -> When the vehicle follows the left wall
  value = leftDistance - rightDistance;
  error = value - setPoint;

  PIDangle = error * Kp
             + (error - lastError) * Kd
             + (integralError * Ki);
  lastError = error;
  if (editParameter == 1) { configureParameters(); }

  if (gameStarted == 1) {
    writeAngleToServo(); 
  }
}




////////////////Obstacle Handling//////////////////////////////////////
void changeSetPoint() {
  if (redObstacleDistance == 0 && greenObstacleDistance == 0) {
    setPoint = 0;
  } else if (redObstacleDistance > greenObstacleDistance) {
    setPoint = 60 ;  //Green obstacle is near the vehicle, so it will try to follow the left wall
  } else if (redObstacleDistance < greenObstacleDistance) {
    setPoint = -60 ;
  }
}

void showParameters() {
  display.clearDisplay();
  display.setCursor(0, 0);
  display.print("P:");
  display.print(Kp);
  display.print(" I:");
  display.print(Ki);
  display.print(" D:");
  display.println(Kd);

  display.print("Speed: ");
  display.println(forwardSpeed);
  display.print("rSteer: ");
  display.println(restrictedSteer);
  display.print("urSteer: ");
  display.println(unrestrictedSteer);
  display.print("Line Intv: ");
  display.println(lineInterval);
  display.print("stopDel: ");
  display.println(stopDelay);


  display.display();
}

void handleSerialCommand(String command) {

  char constant_name = command[0];  //The type of action the remote wants us to take.
  String constant_value_string = command.substring(2, command.length());
  float constant_value = constant_value_string.toFloat();

  if (command == "x") {  // Commands the car to stop
    stopGame();
  } else if (command == "y") {
    startGame();
  } else {
    switch (constant_name) {
      case 'r':  // Raspberry pie is ready for
        Serial.print("a:");
        Serial.println(lineInterval);
        Serial.print("b:");
        Serial.println(stopDelay);
        delay(500);
        digitalWrite(ledPin, HIGH);
        break;
      case 'b':  // Blue line is encountered before the orange line in the runtime of the python script -> round is anti-clockwise
        setPointMultiplier = 1;
        changeSetPoint();  //Fix the sign of the setpoint
        break;
      case 'o':  // Orange line is encountered before the blue line in the runtie of the python script -> round is clockwise
        setPointMultiplier = -1;
        changeSetPoint();  //Fix the sign of the setpoint
        break;
      case 'R':                                     //Red obstacle's distance
        redObstacleDistance = int(constant_value);  // obstacle distance will be 0 when it is beyond the vision range of the vehicle
        changeSetPoint();
        break;
      case 'G':                                       //Green obstacle's distance
        greenObstacleDistance = int(constant_value);  // obstacle distance will be 0 when it is beyond the vision range of the vehicle
        changeSetPoint();
        break;

      case 'p':  //Proportional of PID
        Kp = constant_value;
        preferences.putDouble("Kp", Kp);
        break;
      case 'd':  //Derivative of PID
        Kd = constant_value;
        preferences.putDouble("Kd", Kd);
        break;
      case 's':  //Speed of vehicle
        forwardSpeed = int(constant_value);
        preferences.putInt("speed", forwardSpeed);
        break;

      case 'm':  //MidAngle setup of the steering servo
        Serial.println(int(constant_value));
        steering_servo.write(int(constant_value));
        break;

      default:
        break;
    }
  }
}

void configureParameters() {
  display.clearDisplay();
  display.setCursor(0, 0);

  if (parameterIndex <= 2) {
    display.clearDisplay();
    display.setCursor(0, 0);
    display.print("L:");
    display.print(leftDistance);
    display.print(" F:");
    display.print(frontDistance);
    display.print(" R:");
    display.println(rightDistance);
    if (editParameter == 1 && parameterIndex == 0) {
      writeAngleToServo();
      display.print("> ");
    }
    display.print("A:");
    display.print(int(PIDangle));
    display.print("* SP:");
    display.println(setPoint);
  }
  if (parameterIndex <= 3) {
    if (editParameter == 1 && parameterIndex == 1) { display.print("> "); }
    display.print("Speed: ");
    display.println(forwardSpeed);
    display.println();
  }

  if (parameterIndex <= 4) {
    if (editParameter == 1 && parameterIndex == 2) { display.print("> "); }
    display.print("Kp:");
    display.println(Kp);
    display.println();
  }

  if (parameterIndex <= 5) {
    if (editParameter == 1 && parameterIndex == 3) { display.print("> "); }
    display.print("Ki:");
    display.println(Ki);
    display.println();
  }

  if (parameterIndex <= 6) {
    if (editParameter == 1 && parameterIndex == 4) { display.print("> "); }
    display.print("Kd:");
    display.println(Kd);
    display.println();
  }

  if (parameterIndex <= 7) {
    if (editParameter == 1 && parameterIndex == 5) { display.print("> "); }
    display.print("LineIntv: ");
    display.println(lineInterval);
    display.println();
  }

  if (parameterIndex <= 8) {
    if (editParameter == 1 && parameterIndex == 6) { display.print("> "); }
    display.print("StopDel: ");
    display.println(stopDelay);
    display.println();
  }

  if (parameterIndex <= 9) {
    if (editParameter == 1 && parameterIndex == 7) { display.print("> "); }
    display.print("rSteer: ");
    display.println(restrictedSteer);
    display.println();
  }

  if (parameterIndex <= 10) {
    if (editParameter == 1 && parameterIndex == 8) { display.print("> "); }
    display.print("urSteer: ");
    display.println(unrestrictedSteer);
    display.println();
  }

  display.println();
  display.display();
}


void handleButtonPress() {
  if (button2Flag == 0 && digitalRead(button2Pin) == LOW) {  //Detected a press for button2
    button2Flag = 1;
    pressTime2 = millis();
    delay(300);
  }

  if (button2Flag == 1 && digitalRead(button2Pin) == HIGH) {  //Detected the release for button2
    long gap = millis() - pressTime2;
    if (gap < 500) {
      if (editParameter == 0) {
        stopGame();
      } else if (editParameter == 1) {
        switch (parameterIndex) {
          case 1:
            forwardSpeed -= (forwardSpeed >= 2) ? 2 : 0;
            break;
          case 2:
            Kp -= 0.5;
            break;
          case 3:
            Ki -= 0.05;
            break;
          case 4:
            Kd -= 0.05;
            break;
          case 5:
            lineInterval -= 50;
            break;
          case 6:
            stopDelay -= (stopDelay >= 50) ? 50 : 0;
            break;
          case 7:
            restrictedSteer -= (restrictedSteer > 0) ? 1 : 0;
            break;
          case 8:
            unrestrictedSteer -= (unrestrictedSteer > 0) ? 1 : 0;
            break;
          default:
            break;
        }
      }

    } else if (gap <= 1500)  // Going one step up in the edit parameter menu
    {
      parameterIndex--;
      if (parameterIndex < 0) { parameterIndex = parameterCount - 1; }
    }

    else if (gap > 2500) {
      Serial.write('d');  //Commands the SBC to shutdown
    }
    button2Flag = 0;  //Resetting the flag to detect next presses.
  }

  if (button1Flag == 0 && digitalRead(buttonPin) == LOW)  // We've detected a press in button1
  {
    button1Flag = 1;
    pressTime1 = millis();
    delay(300);
  }

  if (button1Flag == 1 && digitalRead(buttonPin) == HIGH)  // We've detected a release, and will take action according to the pressTime.
  {
    long gap = millis() - pressTime1;
    if (gap < 500) {
      if (editParameter == 0) {
        if (gameStarted == 0) {
          startGame();
        }
      } else if (editParameter == 1) {
        switch (parameterIndex) {
          case 1:
            forwardSpeed += 2;
            break;
          case 2:
            Kp += 0.5;
            break;
          case 3:
            Ki += 0.05;
            break;
          case 4:
            Kd += 0.05;
            break;
          case 5:
            lineInterval += 50;
            break;
          case 6:
            stopDelay += 50;
            break;
          case 7:
            restrictedSteer += (restrictedSteer < maxSteer) ? 1 : 0;
            break;
          case 8:
            unrestrictedSteer += (unrestrictedSteer < maxSteer) ? 1 : 0;
            break;

          default:
            break;
        }
      }
    } else if (gap < 1500) {
      parameterIndex = (parameterIndex + 1) % parameterCount;
    } else if (gap < 3000) {
      if (editParameter == 1) {
        saveParameters();
        editParameter = 0;
        // Updates the associated variables in the SBC
        Serial.print("a:");
        Serial.println(lineInterval);
        Serial.print("b:");
        Serial.println(stopDelay);
        showParameters();

      } else if (editParameter == 0) {
        editParameter = 1;
      }
    }
    button1Flag = 0;
  }
}


void saveParameters() {
  preferences.putDouble("Kp", Kp);
  preferences.putDouble("Ki", Ki);
  preferences.putDouble("Kd", Kd);
  preferences.putInt("speed", forwardSpeed);
  preferences.putInt("lineInterval", lineInterval);
  preferences.putInt("stopDelay", stopDelay);
  preferences.putShort("urSteer", unrestrictedSteer);
  preferences.putShort("restrictedSteer", restrictedSteer);
}

void writeAngleToServo() {
  int steer_angle = midAngle;
  if (PIDangle > 0) {
    steer_angle = midAngle - min(steerAngle, int(PIDangle));
  } else {
    steer_angle = midAngle + min(steerAngle, int(abs(PIDangle)));
  }
  steering_servo.write(steer_angle);
}

void startGame() {
  gameStarted = 1;
  Serial.print("r");  //Commands the raspberry pie to restart the line order detection process
  delay(500);         // Waiting for the raspberry
  goForward(forwardSpeed);
  digitalWrite(ledPin, LOW);  // Turning Off the LED to use it as the high setpoint monitor.
}

void stopGame() {
  gameStarted = 0;
  goForward(0);  //Stops the car.
  digitalWrite(in1Pin, LOW);
  digitalWrite(in2Pin, LOW);
  steering_servo.write(midAngle);
}

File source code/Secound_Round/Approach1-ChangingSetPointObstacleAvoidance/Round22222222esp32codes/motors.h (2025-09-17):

// Pin definitions
#define pwmPin 2 // PWM pin for motor speed
#define in1Pin 4 // Direction control
#define in2Pin 16 // Direction control
#define LEDC_CHANNEL 6 // LEDC channel to use

int forwardSpeed = 90; // Out of 255


void goForward(int speed)
{
    digitalWrite(in1Pin, HIGH);
    digitalWrite(in2Pin, LOW);
    ledcWrite(LEDC_CHANNEL, speed);
}

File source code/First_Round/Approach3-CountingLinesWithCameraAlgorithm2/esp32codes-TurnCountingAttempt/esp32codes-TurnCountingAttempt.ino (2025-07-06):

#include <Wire.h> 
#include <MPU6050.h> 

#include <Preferences.h>
#include "motors.h"
#include "button.h"
#include "servo_motor.h"
#include "sonar.h"
#include "display.h"

MPU6050 mpu;               // Create an MPU6050 object

float gyroZ;               // Variable to store Z-axis angular velocity
float angleZ = 0;          // Accumulated Z-axis angular displacement (degrees)

unsigned long lastTime = 0; // Store time of last measurement

Preferences preferences;
double Kp = 0;
double Kd = 0;
int debugPrint = 0;  //Whether we want to print all the variables to the OLED display.
int turnFlag = 0;
int turnCount = 0;
double value = 0;     // Stores the difference between the left and right readings.
double error = 0;     // The difference between value and setpoint.
double lastError = 0; 

double setPoint = 0;  // The amount of difference in reading of the two ultrasonic sensor we want.
//Above one is the initial setPoint which keeps the vehicle centered in a tunnel
double dynamicSetPoint = 0; //This setpoint is assigned after determining the run direction 

String piStatus = "Not ready"; // Whether raspberry pie is ready for image processing

int terminalDistanceThreshold = 80; 

void setup() {
  // put your setup code here, to run once:
  Serial.begin(115200);
  preferences.begin("wrobot", false);
  Kp = preferences.getDouble("Kp", 0);
  Kd = preferences.getDouble("Kd", 0);
  debugPrint = preferences.getInt("dP", 0);  //dP = debugPrint
  forwardSpeed = preferences.getInt("speed", 0);
  dynamicSetPoint = preferences.getDouble("dSetPoint",0); 

  pinMode(ledPin, OUTPUT);
  pinMode(buttonPin, INPUT_PULLUP);
  pinMode(button2Pin, INPUT_PULLUP);
  pinMode(buzzerPin, OUTPUT);
  digitalWrite(buzzerPin, LOW);

  ESP32PWM::allocateTimer(0);
  steering_servo.setPeriodHertz(50);                     // standard 50 hz servo
  steering_servo.attach(steering_servo_pin, 500, 2400);  // attaches the servo on pin 18 to the servo object
  steering_servo.write(midAngle);
  delay(1000);

  ledcSetup(LEDC_CHANNEL, 1000, 8);     // Set LEDC channel, frequency, and resolution
  ledcAttachPin(pwmPin, LEDC_CHANNEL);  // Attach the GPIO pin to the LEDC channel
  pinMode(in1Pin, OUTPUT);
  pinMode(in2Pin, OUTPUT);

  display.begin(SSD1306_SWITCHCAPVCC, 0x3C);
  display.setTextColor(1);
  display.setTextSize(1);
  display.clearDisplay();

  mpu.initialize();              // Initialize MPU6050 sensor
  if (!mpu.testConnection()) {
    Serial.println("MPU6050 connection failed!");
    while (1);                   // Halt if sensor not found
  }

  Serial.println("MPU6050 initialized successfully.");
  lastTime = millis();           // Initialize time reference
}

void loop() {
  if (Serial.available()) {
    String command = Serial.readStringUntil(';');

    char constant_name = command[0];  //The type of action the remote wants us to take.
    String constant_value_string = command.substring(2, command.length());
    // Serial.print("constant_value_string = ");
    // Serial.println(constant_value_string);
    float constant_value = constant_value_string.toFloat();
    // Serial.print("constant value = ");
    // Serial.println(constant_value); //Though there are more decimal places in the variable,
    //                                 // the print function only prints upto two decimal places
    if (command == "x") {  // Commands the car to stop
      gameStarted = 0;
      goForward(0);
      steering_servo.write(midAngle);
    } else if (command == "y") {
      gameStarted = 1;
      goForward(forwardSpeed);
    } else {
      switch (constant_name) {
        case 'o': //There's orange line before blue , round is clockwise
          setPoint = dynamicSetPoint; 
          break; 
        case 'b': //There's blue line before orange , round is anticlockwise
          setPoint = (-1)*dynamicSetPoint; 
          break; 
        case 'p':  //Proportional of PID
          Kp = constant_value;
          preferences.putDouble("Kp", Kp);
          break;
        case 'd':  //Derivative of PID
          Kd = constant_value;
          preferences.putDouble("Kd", Kd);
          break;
        case 's':  //Speed of vehicle
          forwardSpeed = int(constant_value);
          preferences.putInt("speed", forwardSpeed);
          break;
        case 'D':  //Debug print flag
          debugPrint = int(constant_value);
          preferences.putInt("dP", debugPrint);
          display.clearDisplay();
          display.display();
          break; 

        case 'S': //dynamic Setpoint setup
          dynamicSetPoint = double(constant_value); 
          terminalDistanceThreshold = dynamicSetPoint; 
          preferences.putDouble("dSetPoint", dynamicSetPoint);
          preferences.end();  // Saves variables to EEPROM
          break; 

        case 'r': // Raspberry pie is ready for 
          piStatus = "ready"; 

        default:
          break;
      }
      preferences.end();  // Saves variables to EEPROM
    }
  }

  int frontDistance = middleSonar.ping_cm();
  
  int leftDistance = leftSonar.ping_cm();
  int rightDistance = rightSonar.ping_cm();
  int backDistance = backSonar.ping_cm();

  


  if (leftDistance == 0) {
    leftDistance = terminalDistanceThreshold;
  } else if (rightDistance == 0) {
    rightDistance = terminalDistanceThreshold;
  }

  if (digitalRead(button2Pin)==LOW) {  //For the time being, we'll stop the second button to stop the car and first button to start the car. 
    gameStarted = 0;
    goForward(0); //Stops the car. 
    digitalWrite(in1Pin, LOW); 
    digitalWrite(in2Pin, LOW); 
    steering_servo.write(midAngle);
    delay(300); //Debounce delay
  }

  value = leftDistance - rightDistance;
  error = value - setPoint;
  // int frontConstant = 40;
  // double multiplier = (frontConstant - frontDistance) * (frontDistance < 20) * frontProportion;
  //   if (multiplier == 0) { multiplier = 1; }
  double PIDangle = error * Kp + (error - lastError) * Kd;
  lastError = error;

   // Get the current time
  unsigned long currentTime = millis();                // Current time in ms
  float dt = (currentTime - lastTime) / 1000.0;        // Convert to seconds
  lastTime = currentTime;                              // Update lastTime for next loop

  // Read gyroscope raw data (in degrees/sec)
  gyroZ = mpu.getRotationZ() / 131.0;  // Convert raw to deg/sec (131 LSB/(°/s) for ±250°/s range)

  // Integrate angular velocity to find angular displacement
  angleZ += gyroZ * dt;  // Δθ = ω × Δt

  // Output results
  // Serial.print("Gyro Z (deg/s): ");
  // Serial.print(gyroZ);
  // Serial.print(" | Total Angle Z (°): ");
  // Serial.println(angleZ);

 // delay(10); // Small delay (~100Hz sampling rate)
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

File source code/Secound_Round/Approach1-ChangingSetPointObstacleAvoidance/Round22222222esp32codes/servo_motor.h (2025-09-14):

#include <ESP32Servo.h>

Servo steering_servo;
#define steering_servo_pin 17
// #define rightAngle 25
// #define midAngle 70
// #define leftAngle 115

#define maxSteer 65

float halfAngleRange = 45; //Maximum angle it can go from the centre. 

#define midAngle 92
#define leftAngle midAngle - halfAngleRange
#define rightAngle midAngle + halfAngleRange

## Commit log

2025-05-20 Create arduino code.ino
    Main arduino code folder has been added
2025-05-20 Update arduino code.ino
    Pasted arduino ide code into the folder.
2025-05-22 Added local arduino codebase
2025-05-22 Deleted vs-code compatible arduino codebase
2025-05-22 Added arduino compatible
2025-05-23 Stable version 1
    1. Added button
    2. Added led for turn indication
    3. Proportional turning working perfectly
2025-05-24 Create esp32codes
2025-05-25 Made the entire code ESP32 compatible
    0. Created ESP32 code folder.
    1. Added example esp32 + servo driving simple code folder.
    2. Converted whole arduino nano code to esp32 compatible code
2025-05-26 Added OLED display
    OLED display prints the distance reading of the 3 sonar sensors.
2025-05-26 PID inclusion and moderate quality full turn
    1. Introduced only Kp
    2. Added method to update pid constants value using the serial monitor
    3. Added method to save the constants to EEPROM
2025-05-27 PD_Start_Stop
    1. Added derivative in PID
    2. Added a Learnings text file for documenting what works and what doesn't.
    3. Added vehicle starting and stopping feature via serial command
    [MPU6050_Y_axis_total_angle.ino, MPU6050_Z_axis_total_angle.ino, MPU6050_angular_displacement_calculation_along_X_axis.ino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]
2025-05-29 Added basic Raspberry pin GPIO acces code
2025-05-30 Pyserial communication
    Added Basic ESP32 to Raspberry pie serial communication code
2025-06-04 Added code files
    1. Added debugPrint preference in esp32 code
    2. Added basic serial communication sketch in Raspberry pie code for starting and stopping the car
2025-06-05 Fixed debug print on condition
    [Basic serial communication.py, esp32codes.ino]
2025-06-06 Stable version of Blue traffic sign
    1. Modified ESP32 code to stop the car with command "x;" and start the car with command "y;"
    2. Made the stable version of car stopping by blue traffic sign in Raspberry pie codes
2025-06-09 Implemented non-repetitive start and stop command
    Once the raspberry pi has sent start command, it can now only send an STOP command. And now, it can only send START command. No repetitive command is allowed.
2025-06-10 Update [03] Stopping and Starting car using traffic signs.py
    Added static serial com port address 'esp32_serial'
2025-06-12 Fixed RGB to BGR issue of picamera
    [[02] Color Picker using piecam v1.3.py]
2025-06-22 Changes for permanent circuit on vero board
    1. Added second button pin declaration
    2. Added buzzer functionality
    3. Added back sonar sensor reading
    [button.h, esp32codes.ino]
2025-06-24 Infrared sensor inclusion
    1. Taking analog reading from the VP pin
2025-06-25 Sonar Testing
2025-06-27 testing servo and motor
2025-06-28 fing the sonar pin from previous code
2025-06-30 change rotation motor direction
2025-06-30 blue line detection and PID Bot Runing
2025-07-02 esp32 codes with ML, It Stops bot after 3 laps
2025-07-02 Added main folders of the repository
    Also added the .stl files in the model folder
    [3mm lego stopper.stl, Back sonar holder.stl, Chasis.stl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]
2025-07-02 Added schematics folder
    And the contents inside
2025-07-02 Updated first round esp32 code
    1. Removed unnecessary testing steering at setup
    2. Enabled the servo motor to be its appropriate ranges
    3. set halfAngleRange to it's appropriate value
2025-07-03 Removed previously sonar based turning
2025-07-04 Developed order logic
    And added direction receiving command to esp32
2025-07-04 updated esp32 code for first round approach3
    Included esp32 to raspberry pie talking logic, instead of terminating the python program completely, raspberry pie will wait for esp32's commands to again start the line order detection process for a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
2025-07-04 Implemented setPoint reset mechanism
    [button.h, esp32codes.ino]
2025-07-05 Update esp32codes.ino
    Now, esp32 knows whether raspberry pie is ready for image processing.
2025-07-06 Stable first run version without stopping
    Fixed the overturning issue by limiting steering range.
    [MPU6050_Z_axis_total_angle.ino, button.h, esp32codes-TurnCountingAttempt.ino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]
2025-07-15 Added setpoint changing upon encountering obstacle
    1. Renamed files for more clarity
    2. Added set point changing mechanism upon encountering obstacle in the esp32 code
2025-07-15 Added python code for camera focal length finding
2025-07-16 Improved 2nd round code
    1. Fixed raw frame stream error by introducing small delay by cv2.waitKey(1)
    2. Fixed unicode conversion error
    [Obstacle distances calculator.py, Sending data to ESP32.py, [04] WRO obstacle distance calculator.py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]
2025-07-17 implemented 2nd round ideas
    1. Fixed continuos serial data printing issue.
    2. Introduced functionality to stop and start the car by pressing a keyboard button
    [Obstacle distances calculator.py, esp32codes.ino]
2025-07-18 Implemented basic colorwise obstacle avoidance.
    [Obstacle distances calculator.py]
2025-08-20 Update README.md
    Added raspberry pie setup method via ethernet cable.
2025-08-20 Update README.md
    Added guidline for connecting pie via wireless lan
2025-08-23 Shutdown raspi via esp32 serial command
2025-08-31 Implemented easier control
    1. Removed the two redundant sonar sensor reading.
    2. Implemented parameter tweaking by buttonpress.
2025-09-02 Implemented I in pid
2025-09-02 Fixed sonar reading error
    [Round1esp32codes.ino, Round2esp32codes.ino]
2025-09-06 changed steering strategy
